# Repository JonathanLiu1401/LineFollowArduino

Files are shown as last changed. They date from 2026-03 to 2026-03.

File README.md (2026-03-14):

# UW EE201: Autonomous Line Following Robot

🏆 **All-Time Record Holder:** This robot achieved the all-time fastest track record of **24.5 seconds** in the University of Washington EE201 Line Following Car Competition, securing first place by a margin of over 6 seconds.

This repository contains the complete hardware, mechanical, and software design files for our group's autonomous line-following robot. The system features a custom 3D printed chassis, a bespoke sensor array PCB, and an advanced Arduino-based closed-loop PID control system optimized for aggressive cornering and high-speed straightaways.

## Performance Demonstration

**Record-Breaking 24.5s Run:**
<video src="20260305_180107.mp4" controls="controls" style="max-width: 100%;">
  Your browser does not support the video tag.
</video>

**Robot Overview:**
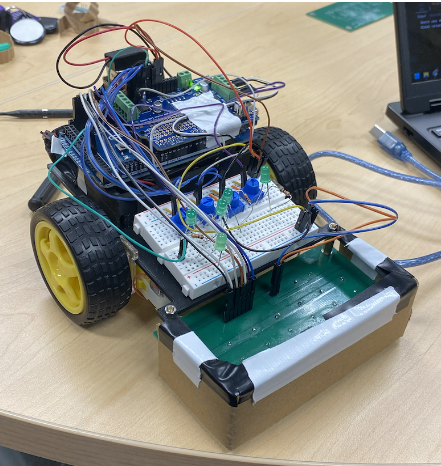
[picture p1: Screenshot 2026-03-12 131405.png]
Robot Screenshot


## Repository Structure

Based on the root directory, the project files are organized as follows:

* **`ee201_final_project_sensor_array/`**
  Contains the schematic and board layout files for the custom 7-sensor Light Dependent Resistor (LDR) analog front-end and tuning interface.
* **`EE201_group6_chassis.stl`**
  The 3D CAD file for the custom-designed robot chassis, optimized for a low center of gravity and precise sensor-to-ground focal distance.
* **`final_line_follower.ino`**
  The final, competition-winning firmware featuring time-based dynamic throttling and quadratic error scaling.
* **`10_5_line_follower_code.ino`**
  A legacy development iteration of the line following logic.

## Hardware Architecture

### Electronics and PCB Design
The electrical system is driven by an Arduino Mega interfaced with an Adafruit Motor Shield V2. A custom PCB was engineered to streamline the analog front-end.
* **Sensor Array:** Seven LDRs configured in voltage divider circuits, spaced precisely to capture standard competition line widths.
* **Control Interface:** Four onboard potentiometers routed to analog pins (A0 through A3) allow for live parameter tuning of Speed, Proportional, Integral, and Derivative gains without requiring firmware recompilation.

### Mechanical Design
The mechanical chassis was manufactured via 3D printing to house the hardware securely. 
* It securely mounts the DC motors, battery payload, and microcontroller stack to prevent center-of-gravity shifts during high-speed cornering. 
* It integrates the sensor mount to keep the LDR PCB at a fixed, optimal distance from the track surface to maximize the black-to-white contrast ratio.

## Software Architecture

The primary firmware (`final_line_follower.ino`) is built in C++ and implements an advanced kinematic control loop. To achieve the record-breaking 24.5 second time, several major algorithmic optimizations were implemented to completely replace the baseline starter code logic.

### Algorithmic Advancements

* **Temporal Dynamic Throttling:** The baseline code utilized a static speed output. The winning firmware implements a clock-driven control state that tracks execution time using the hardware `millis()` timer. Between 8.5 seconds and 17.5 seconds into the run, the algorithm mathematically divides the user-defined speed boost by a factor of 2.3. This ensures the robot maintains absolute maximum velocity on the starting and ending straightaways while automatically decelerating to navigate the dense stacked-turn section with maximum grip.
* **Quadratic Proportional Gain:** The original PID implementation calculated the proportional turning force linearly. The updated control loop scales the proportional error quadratically. By multiplying the error by its absolute ratio over the maximum possible error, the algorithm heavily attenuates steering corrections near the center line. This eliminates high-speed straight-line wobbling while retaining 100 percent control authority at the extreme sensor edges for 90-degree pivots.
* **Exponential Moving Average (EMA) Derivative Filter:** The original raw discrete derivative calculation was highly susceptible to analog sensor noise, causing jitter. The modified code passes the raw derivative through an EMA low-pass filter with a smoothing factor of 0.4. This prevents erratic micro-corrections and allows the system to support a significantly higher derivative gain (kD = 170) to dampen overshoots during aggressive cornering.
* **Asynchronous Hardware Polling:** The starter code executed analog-to-digital conversions to read all four potentiometers during every loop iteration. The winning code introduces a modulo counter to restrict potentiometer polling to once every 5000 loop cycles. This dramatically reduces loop execution time, allowing the microcontroller to sample the photoresistors and update the motor PWM outputs at a much higher frequency. 
* **Rapid Static-State Calibration:** The original calibration sequence utilized synchronous LED blinking (`delay()` based logic) to indicate sampling progress, which artificially bottlenecked the processor and dragged the 40-sample process out to over 20 seconds. We stripped out the blocking blink logic and replaced it with a static LED indicator. This optimization slashed the total calibration time down to just 5 seconds, vastly improving pre-race setup efficiency without sacrificing sensor accuracy.
* **Hardware Safety Interlocks:** A dedicated safety algorithm continuously monitors the raw sensor array data to detect abnormal environmental states. If the system detects all darkness (indicating the robot has been lifted or driven off a table) or all white (indicating total line loss), it circumvents the PID calculation and instantly cuts power to the drive motors to prevent runaway hardware damage.

## Setup and Calibration

1. **Hardware Assembly:** Mount the Arduino, Motor Shield, and DC motors to the 3D printed chassis. Connect the custom PCB to the analog header block.
2. **Firmware Upload:** Flash `final_line_follower.ino` to the Arduino Mega.
3. **Calibration Sequence:**
    * Power the robot on while placing the sensor array strictly over the **white** surface.
    * Wait for the onboard LED indicator to turn on, signaling active white calibration.
    * Move the robot so the sensor array is directly over the **black** line during the 1-second delay window.
    * The robot will complete the black calibration, start the internal race clock, and immediately engage the motors.

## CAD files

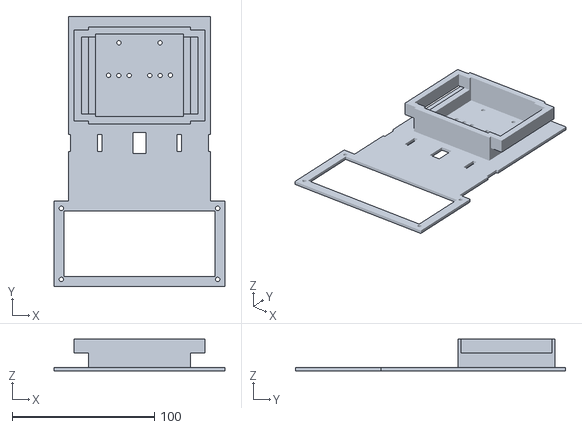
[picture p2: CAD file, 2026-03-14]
EE201_group6_chassis.stl
120.0 x 190.0 x 22.5

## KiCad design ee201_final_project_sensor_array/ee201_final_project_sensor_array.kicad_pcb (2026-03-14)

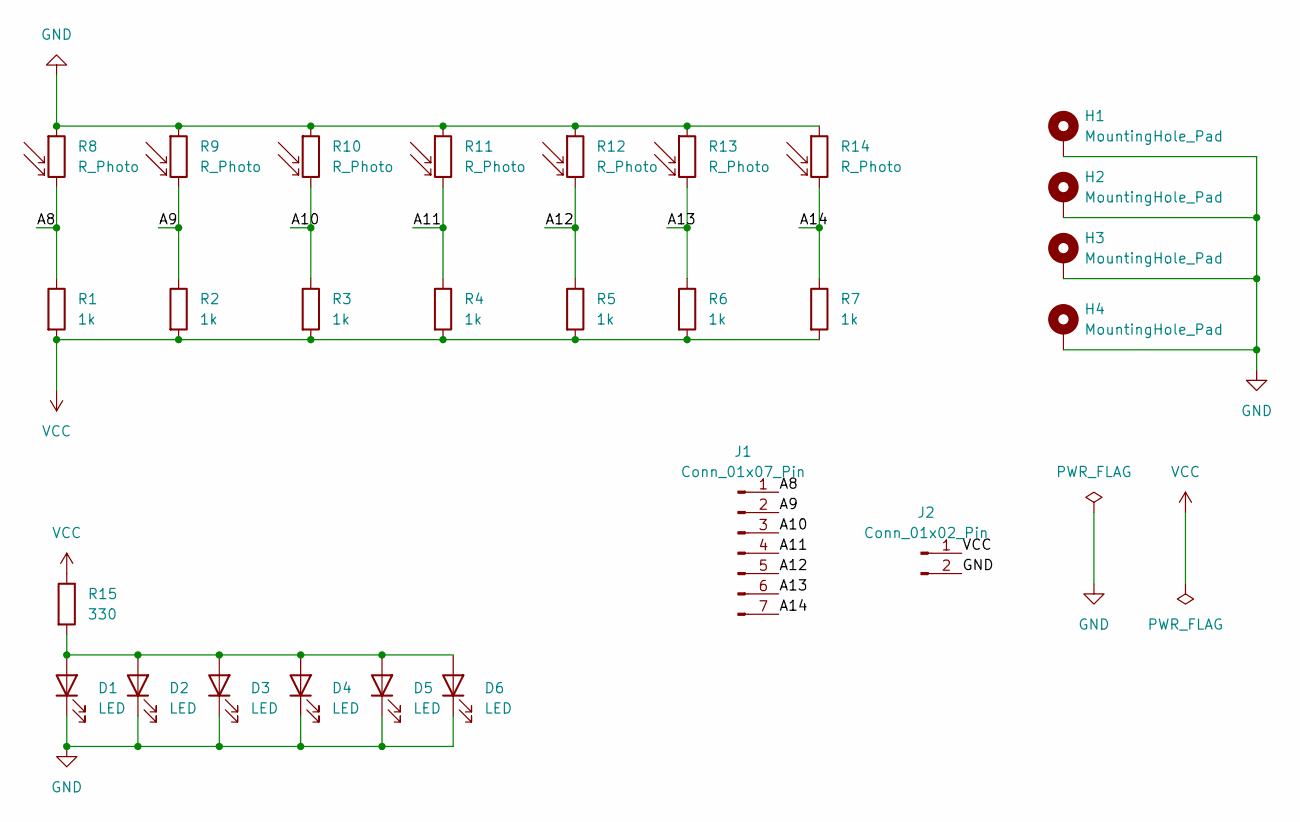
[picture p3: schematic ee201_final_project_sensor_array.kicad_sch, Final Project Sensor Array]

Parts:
D1, D2, D3, D4, D5, D6: LED; LED_D5.0mm
H1, H2, H3, H4: MountingHole_Pad; MountingHole_3.2mm_M3_Pad
J1: Conn_01x07_Pin; PinHeader_1x07_P2.54mm_Vertical
J2: Conn_01x02_Pin; PinHeader_1x02_P2.54mm_Vertical
R1, R2, R3, R4, R5, R6, R7: 1k; R_Axial_DIN0207_L6.3mm_D2.5mm_P10.16mm_Horizontal
R8, R9, R10, R11, R12, R13, R14: R_Photo; R_LDR_5.0x4.1mm_P3mm_Vertical
R15: 330; R_Axial_DIN0207_L6.3mm_D2.5mm_P10.16mm_Horizontal

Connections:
/A8: J1.1, R1.1, R8.2
/A9: J1.2, R2.1, R9.2
/A10: J1.3, R3.1, R10.2
/A11: J1.4, R4.1, R11.2
/A12: J1.5, R5.1, R12.2
/A13: J1.6, R6.1, R13.2
/A14: J1.7, R7.1, R14.2
GND: D1.1 (K), D2.1 (K), D3.1 (K), D4.1 (K), D5.1 (K), D6.1 (K), H1.1, H2.1, H3.1, H4.1, J2.2, R8.1, R9.1, R10.1, R11.1, R12.1, R13.1, R14.1
unnamed: D1.2 (A), D2.2 (A), D3.2 (A), D4.2 (A), D5.2 (A), D6.2 (A), R15.2
VCC: J2.1, R1.2, R2.2, R3.2, R4.2, R5.2, R6.2, R7.2, R15.1

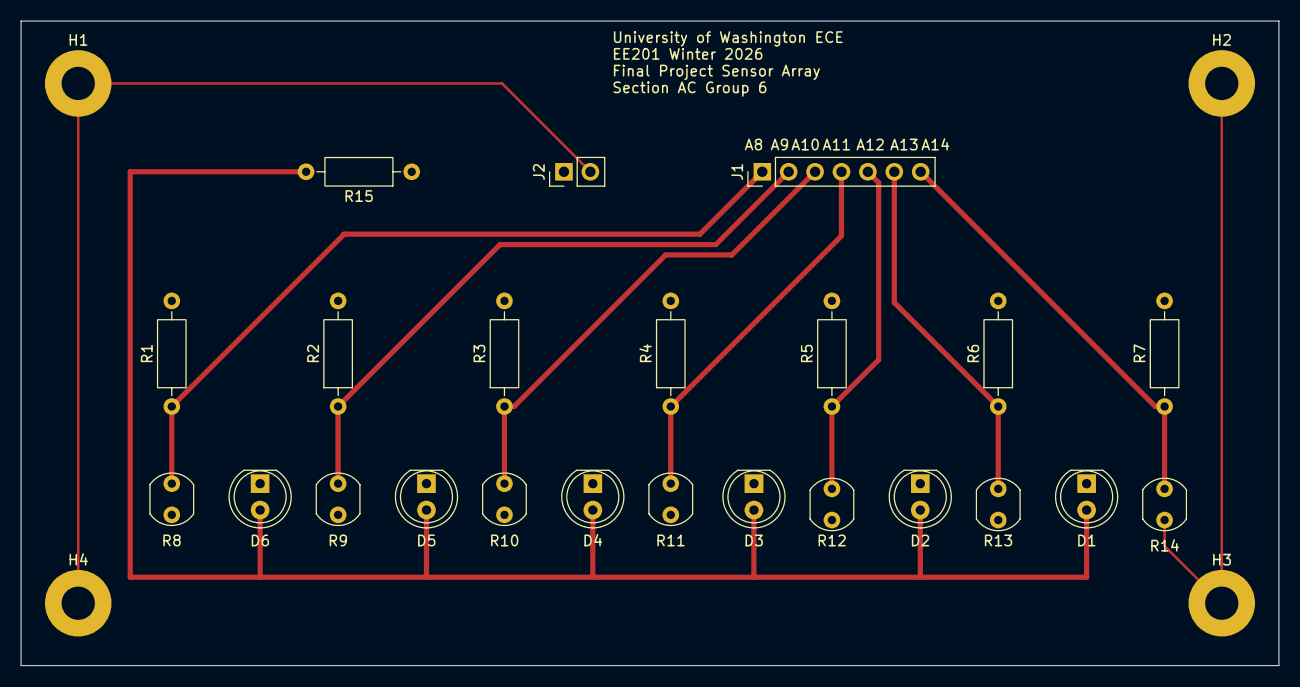
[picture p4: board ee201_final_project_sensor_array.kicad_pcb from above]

Board: 2 copper layers, 121.0 x 62.0 mm, 27 parts (0 on the bottom side), 10 nets.

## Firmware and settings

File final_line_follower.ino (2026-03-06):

/* ************************************************************************************************* */
// * ECE 201: Line Following Robot with PID                                                         *
/* ************************************************************************************************* */

#include <Wire.h>
#include <Adafruit_MotorShield.h>

Adafruit_MotorShield AFMS = Adafruit_MotorShield();
Adafruit_DCMotor *Motor1 = AFMS.getMotor(1); // left motor
Adafruit_DCMotor *Motor2 = AFMS.getMotor(2); // right motor

const int M1Sp = 60;
const int M2Sp = 60;

const int S_pin = A0;
const int P_pin = A1;
const int I_pin = A2;
const int D_pin = A3;

const float speed      = 140;
const float proportion = 120;
const float max_k_drop = 80;
const float derivative = 170;

float previous_derivative = 0.0;
float alpha = 0.4;

const int numMeas = 40;

int   SpRead      = 0;
int   kPRead      = 0;
float K_drop_read = 0;
int   kDRead      = 0;

int LDR_Pin[7] = {A8, A9, A10, A11, A12, A13, A14};
int LDR[7];
int led_Pin = 32;

float Mn[7];
float Mx[7];
float LDRf[7] = {0., 0., 0., 0., 0., 0., 0.};

int   MxRead;
int   MxIndex;
float AveRead;
int   CriteriaForMax;
float WeightedAve;

int im0, im1, im2;

int   M1SpeedtoMotor, M2SpeedtoMotor;
int   Turn;
int   M1P = 0, M2P = 0;
float error     = 0.0;
float lasterror = 0.0;
int   sumerror  = 0;
float kP, kI, kD;
int   counter   = 0;

unsigned long runStartTime = 0; // set after calibration — clock starts when car begins moving

// ************************************************************************************************* //
void setup() {
  Serial.begin(9600);
  AFMS.begin();
  pinMode(led_Pin, OUTPUT);
  Calibrate();
  ReadPotentiometers();
  runStartTime = millis(); // start clock here, after calibration
  RunMotors();
}

// ************************************************************************************************* //
void loop() {
  ReadPhotoResistors();

  if (counter % 5000 == 0) {
    ReadPotentiometers();
  }
  counter++;

  if (CheckSafety() == false) {
    EmergencyStop();
    return;
  }

  CalcError();
  PID_Turn();
  RunMotors();

  // Print();
}

// ************************************************************************************************* //
bool CheckSafety() {
  int darkCount  = 0;
  int whiteCount = 0;
  for (int i = 0; i < 7; i++) {
    if (LDR[i] > 90) darkCount++;
    if (LDR[i] < 15) whiteCount++;
  }
  if (darkCount  >= 6) return false;
  if (whiteCount >= 7) return false;
  return true;
}

// ************************************************************************************************* //
void EmergencyStop() {
  Motor1->run(RELEASE); Motor2->run(RELEASE);
  Motor1->setSpeed(0);  Motor2->setSpeed(0);
}

// ************************************************************************************************* //
void Calibrate() {
  digitalWrite(led_Pin, HIGH);
  for (int calii = 0; calii < numMeas; calii++) {
    for (int ci = 0; ci < 7; ci++) { LDRf[ci] += (float)analogRead(LDR_Pin[ci]); delay(2); }
  }
  digitalWrite(led_Pin, LOW);
  for (int cm = 0; cm < 7; cm++) { Mn[cm] = round(LDRf[cm] / (float)numMeas); LDRf[cm] = 0.; }

  delay(1000);

  digitalWrite(led_Pin, HIGH);
  for (int calii = 0; calii < numMeas; calii++) {
    for (int ci = 0; ci < 7; ci++) { LDRf[ci] += (float)analogRead(LDR_Pin[ci]); delay(2); }
  }
  digitalWrite(led_Pin, LOW);
  for (int cm = 0; cm < 7; cm++) { Mx[cm] = round(LDRf[cm] / (float)numMeas); LDRf[cm] = 0.; }
}

// ************************************************************************************************* //
void ReadPotentiometers() {
  SpRead      = map(analogRead(S_pin), 0, 1023, 0, speed);
  kPRead      = map(analogRead(P_pin), 0, 1023, 0, proportion);
  K_drop_read = map(analogRead(I_pin), 0, 1023, 0, max_k_drop);
  kDRead      = map(analogRead(D_pin), 0, 1023, 0, derivative);
}

// ************************************************************************************************* //
void RunMotors() {
  // After 15s, halve the potentiometer speed boost for the stacked turn section
  int effectiveSpRead = (millis() - runStartTime < 8500 || millis() - runStartTime >= 17500)
                      ? SpRead : SpRead / 2.3;

  int currentBaseSpeed1 = M1Sp + effectiveSpRead;
  int currentBaseSpeed2 = M2Sp + effectiveSpRead;

  M1SpeedtoMotor = constrain(currentBaseSpeed1 + M1P, -255, 255);
  M2SpeedtoMotor = constrain(currentBaseSpeed2 + M2P, -255, 255);

  Motor1->setSpeed(abs(M1SpeedtoMotor));
  Motor2->setSpeed(abs(M2SpeedtoMotor));
  Motor1->run(M1SpeedtoMotor > 0 ? FORWARD : BACKWARD);
  Motor2->run(M2SpeedtoMotor > 0 ? FORWARD : BACKWARD);
}

// ************************************************************************************************* //
void ReadPhotoResistors() {
  for (int Li = 0; Li < 7; Li++) {
    LDR[Li] = map(analogRead(LDR_Pin[Li]), Mn[Li], Mx[Li], 0, 100);
  }
}

// ************************************************************************************************* //
void CalcError() {
  MxRead  = -99;
  AveRead = 0.0;

  for (int i = 0; i < 7; i++) {
    if (MxRead < LDR[i]) { MxRead = LDR[i]; MxIndex = -1 * (i - 3); im1 = i; }
    AveRead += (float)LDR[i] / 7.0;
  }

  CriteriaForMax = 2;
  if (MxRead > CriteriaForMax * AveRead) {
    if (im1 != 0 && im1 != 6) {
      im0         = im1 - 1;
      im2         = im1 + 1;
      WeightedAve = ((float)(LDR[im0]*im0 + LDR[im1]*im1 + LDR[im2]*im2))
                  / ((float)(LDR[im0] + LDR[im1] + LDR[im2]));
      error       = -1.0 * (WeightedAve - 3.0);
    } else if (im1 == 0) {
      im2         = im1 + 1;
      WeightedAve = ((float)(LDR[im1]*im1 + LDR[im2]*im2))
                  / ((float)(LDR[im1] + LDR[im2]));
      error       = -1.0 * (WeightedAve - 3.0);
    } else {
      im0         = im1 - 1;
      WeightedAve = ((float)(LDR[im0]*im0 + LDR[im1]*im1))
                  / ((float)(LDR[im0] + LDR[im1]));
      error       = -1.0 * (WeightedAve - 3.0);
    }
  } else {
    error = -1.0 * (im1 - 3.0);
  }

  if (isnan(error)) error = lasterror;
}

// ************************************************************************************************* //
void PID_Turn() {
  kP = (float)kPRead;
  kI = 0.0;
  kD = (float)kDRead;

  float raw_derivative      = error - lasterror;
  float filtered_derivative = (alpha * raw_derivative) + ((1.0 - alpha) * previous_derivative);
  previous_derivative       = filtered_derivative;

  float quadratic_P = kP * error * (abs(error) / 3.0);
  Turn = (int)(quadratic_P + (sumerror * kI) + (filtered_derivative * kD));

  sumerror += (int)error;
  if      (sumerror >  5) sumerror =  5;
  else if (sumerror < -5) sumerror = -5;

  lasterror = error;

  M1P =  Turn;
  M2P = -Turn;
}

// ************************************************************************************************* //
void Print() {
  Serial.print(Turn);           Serial.print(" ");
  Serial.print(error);          Serial.print(" ");
  Serial.print(sumerror);       Serial.print(" ");
  Serial.print(lasterror);      Serial.print(" ");
  Serial.print("   |   ");
  Serial.print(SpRead);         Serial.print(" ");
  Serial.print(kP);             Serial.print(" ");
  Serial.print(K_drop_read);    Serial.print(" ");
  Serial.print(kD);             Serial.print(" ");
  Serial.print("   |   ");
  for (int i = 0; i < 7; i++) { Serial.print(LDR[i]); Serial.print(" "); }
  Serial.print("   |   ");
  Serial.print(MxRead);         Serial.print(" ");
  Serial.print(MxIndex);        Serial.print(" ");
  Serial.print(error);          Serial.print(" ");
  Serial.print("   |   ");
  Serial.print(M1SpeedtoMotor); Serial.print(" ");
  Serial.println(M2SpeedtoMotor);
  delay(200);
}

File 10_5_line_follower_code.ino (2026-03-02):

/* ************************************************************************************************* */
// * ECE 201: Line Following Robot with PID + Safety Logic * //
/* ************************************************************************************************* */

// ************************************************************************************************* //
// Declare Variables

// Variables and Libaries for Motor
#include <Wire.h>
#include <Adafruit_MotorShield.h> 

Adafruit_MotorShield AFMS = Adafruit_MotorShield();
// Motors can be switched here (1) <--> (2)
Adafruit_DCMotor *Motor1 = AFMS.getMotor(1); // left motor
Adafruit_DCMotor *Motor2 = AFMS.getMotor(2); // right motor
  
// Set Initial Speed of Motors (CAN BE EDITED BY USER)
// Default speed set to 60 as recommended
const int M1Sp = 60; 
const int M2Sp = 60;

// Variables for Potentiometer
// Assigned to Analog pins A0-A3
const int S_pin = A0; //proportional control
const int P_pin = A1; //proportional control
const int I_pin = A2; //integral control
const int D_pin = A3; //derivative control

// User set SPID values
// These are the MAXIMUM values that the potentiometers can map to.
// Tuned for standard line following behavior.
const float speed       = 140; // Max added speed
const float proportion  = 80;  // Max Kp
const float integral    = 5;   // Max Ki (Keep small to prevent windup)
const float derivative  = 80;  // Max Kd

const int numMeas = 30; // setting numMeas to 40 as in code 10.4 is recommended

// Initialize SPID values to zero
int SpRead = 0; //Speed Increase 
int kPRead = 0; //proportional gain
int kIRead = 0; //integral gain
int kDRead = 0; //derivative gain
  
// Variables for Light Sensors
// LDR_Pin holds 7 values of the LDR pin connection to the Arduino
int LDR_Pin[7] = {A8, A9, A10, A11, A12, A13, A14}; 
int LDR[7]; // this is an empty array that will hold the readings from our potentiometers

// LED Pin (PRESET DO NOT CHANGE)
int led_Pin = 32; 

// Calibration Variables
float Mn[7]; // array containing minimum read values of every potentiometer
float Mx[7]; // array containing maximum read values of every potentiometer
float LDRf[7] = {0.,0.,0.,0.,0.,0.,0.}; // initialize the LDR read values to float zero

int MxRead; // maximum read value by any potentiometer
int MxIndex; // index (location in array) of max read value
float AveRead; // average read value of potentiometer
int CriteriaForMax; // value to determine whether a read value is a max
float WeightedAve; // weighted average after calibration
  
// Error calculation variables
int im0, im1, im2; 
  
// Motor control variables
int M1SpeedtoMotor, M2SpeedtoMotor; // actual speeds motor will be rotating at
int Turn; // which direction and how sharply should the cart turn
int M1P = 0, M2P = 0; // proportion control for motors 1 and 2 respectively
float error; // current error
int lasterror = 0; // previous error
int sumerror = 0; // sum of total errors
float kP, kI, kD; // final values of P, I, and D used in control
 
// ************************************************************************************************* //
// setup - runs once
void setup() {
  Serial.begin(9600); // Standard baud rate
  AFMS.begin(); // initialize the motor

  pinMode(led_Pin, OUTPUT); // set the led_pin to be an output
  
  Calibrate(); // Calibrate black and white sensing
  
  ReadPotentiometers(); // Read potentiometer values (Sp, P, I, & D)
  
  delay(2000); // Delay to ensure cart is properly placed before moving
  
  RunMotors(); // Starts motors straight forward
 
} // end setup()

// ************************************************************************************************* //
// loop - runs/loops forever
void loop() {
  // Note: some functions are only helpful for debugging and can be commented out once functionality is ensured
 
  ReadPotentiometers(); // Only if you want to see Potentiometers working in set up as you run the line following
  
  ReadPhotoResistors(); // Read photoresistors and map to 0-100 based on calibration
  
  // *** SAFETY CHECK ***
  // If CheckSafety returns false, it means danger is detected.
  // We stop the motors and skip the PID calculation.
  if (CheckSafety() == false) {
    EmergencyStop();
    // Do NOT proceed to CalcError or RunMotors
    return; // Restart the loop immediately
  }
  
  CalcError();
  
  PID_Turn(); // PID Control and Output to motors to turn
  RunMotors(); // Uses info from
  
  //Print(); // Print values to serial monitor
 
} // end loop()

// ************************************************************************************************* //
// NEW: SAFETY FUNCTION
// Returns TRUE if it is safe to drive.
// Returns FALSE if the robot is lifted, falling, or completely lost.
bool CheckSafety() {
  int darkCount = 0;
  int whiteCount = 0;

  // Scan all 7 sensors
  for (int i = 0; i < 7; i++) {
    // 1. Detect Darkness (Cliff / Lifted)
    // If sensor reads high (> 90), it sees no reflection (air/cliff) or black line.
    if (LDR[i] > 90) {
      darkCount++;
    }

    // 2. Detect White (Lost Line)
    // If sensor reads low (< 15), it sees only white surface.
    if (LDR[i] < 15) {
      whiteCount++;
    }
  }

  // CONDITION 1: CLIFF DETECTED
  // If 6 or more sensors are "Dark", we are likely in the air or off a cliff.
  if (darkCount >= 6) {
    // Serial.println("SAFETY TRIGGER: CLIFF / LIFTED");
    return false; // Unsafe
  }

  // CONDITION 2: LINE LOST
  // If ALL 7 sensors see white, we have lost the line completely.
  // Stop to prevent wandering into walls.
  if (whiteCount >= 7) {
    // Serial.println("SAFETY TRIGGER: LINE LOST");
    return false; // Unsafe
  }

  return true; // Safe
}

// ************************************************************************************************* //
// NEW: EMERGENCY STOP FUNCTION
void EmergencyStop() {
  Motor1->run(RELEASE);
  Motor2->run(RELEASE);
  Motor1->setSpeed(0);
  Motor2->setSpeed(0);
}

// ************************************************************************************************* //
// function to quickly blink an LED
void fastBlink() {
  digitalWrite(led_Pin, HIGH); // turn on the LED
  delay(100); // wait for 100 milliseconds

  digitalWrite(led_Pin, LOW); // turn off the LED
  delay(100); // wait for 100 milliseconds
} // end fastBlink()

// ************************************************************************************************* //
// function to slowly blink an LED
void slowBlink() {
  digitalWrite(led_Pin, HIGH); // turn on the LED
  delay(100); // wait for 100 milliseconds

  digitalWrite(led_Pin, LOW); // turn off the LED
  delay(900); // wait for 900 milliseconds
} // end slowBlink()
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

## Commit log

2026-03-02 added quadratic error scaling
    quadratic error scaling to reduce oscillations on straight paths
    [final_line_follower.ino]
2026-03-02 Add files via upload
    added quadratic error scaling for kdrop to reduce speed reductions on straight paths
    [final_line_follower.ino]
2026-03-06 24.5 seconds
    Final line follower able to complete UW line following car track in under 24.5s with fully charged battery and high P and D values (~100). Changes include hard coded speed up and slow down sections, 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
2026-03-14 Sensor Array PCB Design
    Designed in KiCAD
    [ee201_final_project_sensor_array-B_Cu.gbr, ee201_final_project_sensor_array-B_Mask.gbr, ee201_final_project_sensor_array-B_Paste.gbr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]
2026-03-14 Chassis
    Chassis stl for 3d print
    [EE201_group6_chassis.stl]
2026-03-14 Initialize README with project overview and setup
    Added detailed documentation for the autonomous line-following robot project, including hardware, software, and calibration instructions.
